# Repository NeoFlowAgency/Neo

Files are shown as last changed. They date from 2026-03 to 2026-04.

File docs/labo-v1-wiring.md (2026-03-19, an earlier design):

# NEO Labo V1 — Guide de câblage rapide

> Projet d'apprentissage : Servo + LEDs + LCD + Clavier 4×4 sur ESP32

---

## Composants nécessaires

- 1× ESP32 DevKit-C
- 1× Servo MG996R (ou SG90 pour commencer)
- 1× LCD 16×2 avec module I2C (adresse 0x27 par défaut)
- 1× Clavier matriciel 4×4
- 3× LEDs (rouge, verte, bleue)
- 3× Résistances 220Ω (une par LED)
- Fils dupont, breadboard

---

## Schéma de branchement

### Servo MG996R (ou SG90)
```
Servo fil BRUN  (GND)    → GND de l'ESP32
Servo fil ROUGE (5V/6V)  → VIN de l'ESP32 (ou alim externe 6V)
Servo fil ORANGE (signal) → GPIO 18
```
> ⚠️ Pour un seul servo en test, le VIN du devkit (5V USB) suffit.
> Pour plusieurs servos lourds, utilise une alim externe.

### LCD 16×2 I2C
```
LCD VCC → 3.3V ou 5V ESP32
LCD GND → GND
LCD SDA → GPIO 21
LCD SCL → GPIO 22
```
> Si l'écran n'affiche rien, tourne le petit potentiomètre bleu
> derrière le module I2C pour ajuster le contraste.

### LEDs
```
LED ROUGE  : anode → GPIO 26 → résistance 220Ω → GND
LED VERTE  : anode → GPIO 27 → résistance 220Ω → GND
LED BLEUE  : anode → GPIO 32 → résistance 220Ω → GND
```
> Sens LED : patte longue = anode (+), patte courte = cathode (−)

### Clavier 4×4
```
 ┌─────────────────────────────────────┐
 │  Clavier  │  Broche  │  GPIO ESP32  │
 ├───────────┼──────────┼──────────────┤
 │  Ligne 1  │   R1     │   GPIO 13    │
 │  Ligne 2  │   R2     │   GPIO 14    │
 │  Ligne 3  │   R3     │   GPIO 16    │
 │  Ligne 4  │   R4     │   GPIO 17    │
 │  Col 1    │   C1     │   GPIO 15    │
 │  Col 2    │   C2     │   GPIO 12    │
 │  Col 3    │   C3     │   GPIO  2    │
 │  Col 4    │   C4     │   GPIO  5    │
 └─────────────────────────────────────┘
```

---

## Librairies Arduino à installer

Dans Arduino IDE → Gestionnaire de bibliothèques :

| Librairie | Auteur |
|---|---|
| `ESP32Servo` | Kevin Harrington |
| `LiquidCrystal I2C` | Frank de Brabander |
| `Keypad` | Mark Stanley / Alexander Brevig |

---

## Contrôles (rappel)

| Touche | Action |
|---|---|
| `1` | Servo → 0° |
| `2` | Servo → 22° |
| `3` | Servo → 45° |
| `4` | Servo → 67° |
| `5` | Servo → 90° (centre) |
| `6` | Servo → 112° |
| `7` | Servo → 135° |
| `8` | Servo → 157° |
| `9` | Servo → 180° |
| `0` | Servo → 90° (centre rapide) |
| `A` | Toggle LED ROUGE |
| `B` | Toggle LED VERTE |
| `C` | Toggle LED BLEUE |
| `D` | Toggle TOUTES les LEDs |
| `*` | Affiche le menu sur LCD |
| `#` | Reset tout (servo 90°, LEDs OFF) |

---

## Problèmes fréquents

**LCD blanc/rien affiché :**
→ Tourne le potentiomètre bleu au dos du module I2C
→ Vérifie l'adresse I2C avec un sketch de scan (chercher "I2C scanner Arduino")

**Servo qui tremble :**
→ Alimente-le en externe (ne pas tirer 5V du port USB de l'ESP32 pour les gros servos)
→ Mets une capa 100µF en parallèle sur l'alim du servo

**Clavier ne répond pas :**
→ Vérifie l'ordre des fils (compte depuis le pin 1 marqué sur le connecteur)
→ Certains claviers ont R1-R4 à gauche, d'autres à droite — inverse les lignes/colonnes si besoin

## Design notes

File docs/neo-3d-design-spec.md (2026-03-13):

# Neo — Spécification 3D (V2)

> Guide de modélisation pour Fusion 360 — imprimante Bambu Lab A1
> Tête Ultron scalée à **250mm de hauteur**

---

## Dimensions de référence : Servo MG996R

```
Longueur : 40.7 mm
Largeur  : 19.7 mm
Hauteur  : 42.9 mm (corps) + ~15 mm axe
Trous de fixation : 49 mm entre-axes (axe long) × 10 mm (axe court)
Diamètre vis fixation : M3
Diamètre axe (horn) : ~6 mm cannelé, 25 dents
Vis de fixation horn : M3 × 8 mm
```

---

## Vue d'ensemble — Hauteurs de la chaîne cinématique

```
┌──────────────────────────────────────────────────────┐
│  TÊTE ULTRON           250 mm  ←── tête scalée       │
│  CAGE INTERNE TÊTE      ~50 mm (structure interne)   │
│  SUPPORT TÊTE           50 mm  (S3 + bras S4/palier) │
│  COU                    80 mm  (creux, passage câble) │
│  BUSTE                 130 mm  (torse Ultron stylisé) │
│  BASE                  100 mm  (électronique)         │
├──────────────────────────────────────────────────────┤
│  HAUTEUR TOTALE        ~610 mm                        │
│  (sans compter les pieds de l'antenne/décoration)     │
└──────────────────────────────────────────────────────┘
```

---

## Contraintes Bambu Lab A1 (volume 256×256×256 mm)

| Pièce | Dims max estimées | Imprimable d'un coup ? |
|---|---|---|
| Tête Ultron | ~180×200×250 mm | ✅ Oui |
| Base | 200×160×100 mm | ✅ Oui |
| Buste | 120×90×130 mm | ✅ Oui |
| Cou | Ø65×80 mm | ✅ Oui |
| Support tête | 160×90×50 mm | ✅ Oui |
| Cage interne | ~170×190×50 mm | ✅ Oui |

> ⚠️ Si la tête Ultron dépasse 256mm en largeur ou profondeur après scaling,
> elle devra être coupée en 2 moitiés (gauche/droite) et collée à la résine.

---

## Passage de câbles — Principe général

```
Base → Buste : gouttière centrale Ø12 mm (4× câbles servo + alim)
Buste → Cou  : gouttière centrale Ø12 mm
Cou → Support: gouttière centrale Ø10 mm
Support → Cage: 2× trous Ø6 mm sur les bras latéraux
```

Câbles concernés par pièce :
- **Base** : ESP32 USB (charge/prog), câble alim 5V/6V servos, câble écran LCD, câble clavier
- **Buste** : câble S1 (sort par bas) + câbles S2/S3/S4 (transit vers haut)
- **Cou** : câbles S3 + S4 en transit
- **Support** : câble S4 local

---

## PIÈCE 1 — BASE

**Fonction :** Boîtier principal — contient toute l'électronique — porte le Servo S1 (rotation torse)

**Dimensions extérieures :**
```
Longueur : 200 mm
Largeur  : 160 mm
Hauteur  : 100 mm
Épaisseur parois : 3 mm (PETG) ou 2.5 mm (PLA+)
```

**Façade AVANT (interface utilisateur) :**
```
Écran LCD 16×2 I2C :
  Fenêtre découpe : 74 mm × 25 mm
  Position : centré horizontalement, à 12 mm du bord supérieur

Clavier matriciel 4×4 :
  Fenêtre découpe : 72 mm × 72 mm
  Position : centré horizontalement, à 10 mm du bord inférieur
  (espace entre LCD et clavier : ~25 mm pour câblage)
```

**Façade LATÉRALE gauche :**
```
Interrupteur marche/arrêt (bouton poussoir ou toggle) : trou Ø7 mm
Potentiomètre volume/réglage : trou Ø7 mm
Passage USB-C ESP32 (charge/programmation) : découpe 10×5 mm
```

**Façade LATÉRALE droite :**
```
Passage câbles servos (gaine spirale) : passage Ø12 mm avec guide
```

**Dessus de la BASE :**
```
Logement servo S1 (MG996R À PLAT, axe vers le haut) :
  Cavité : 44 mm × 22 mm × 25 mm
  4 × trous M3, entraxe 49 mm × 10 mm
  Axe centré en largeur, décalé de 25 mm vers l'arrière
  Ouverture Ø8 mm pour l'axe S1 (vers le haut)

Passage câbles (côté arrière du servo) : gouttière 12×8 mm
```

**Intérieur BASE :**
```
ESP32 DevKit-C (55×28 mm) :
  4 × plots M2.5 hauteur 5 mm, en bas à gauche de la base
  Accès USB-C vers le trou latéral

Porte-batterie / régulateur 6V :
  Zone réservée 80×40 mm côté arrière droit

Gouttières câbles : 2 × gouttières latérales 10 mm de large
```

**Matériau :** PETG
**Infill :** 25%, gyroïde
**Couleur suggérée :** Gris foncé ou noir

---

## PIÈCE 2 — BUSTE

**Fonction :** Torse de Neo — tourne avec S1 — porte S2 (rotation cou)

**Dimensions :**
```
Largeur bas  : 120 mm (s'emboîte sur la base)
Largeur haut : 80 mm
Profondeur   : 75 mm
Hauteur      : 130 mm
Épaisseur paroi : 3 mm
```

**Bas du buste — adaptateur horn S1 :**
```
Plateau circulaire Ø58 mm, épaisseur 5 mm
  4 × trous M3 sur cercle Ø42 mm (vis horn standard)
  Trou central Ø6.5 mm (passage axe)
  Ce plateau descend DANS la base (jeu vertical +0.3 mm → rotation libre)
```

**Haut du buste — logement S2 :**
```
S2 monté À PLAT (axe vers le haut)
Cavité : 44 mm × 22 mm × 25 mm
4 × trous M3, entraxe 49 mm × 10 mm
Axe centré en largeur et profondeur
Ouverture Ø8 mm vers le haut
```

**Passage câbles :**
```
Gouttière centrale verticale Ø12 mm (câbles S2/S3/S4 en transit)
```

**Forme esthétique :**
```
Section trapézoïdale (plus large en bas)
Chanfreins 5 mm sur les arêtes verticales
Style "torse Ultron" (légers creux sur les flancs, optionnel)
```

**Matériau :** PETG
**Infill :** 30%, gyroïde

---

## PIÈCE 3 — COU

**Fonction :** Relie buste et support tête — tourne avec S2 — porte S3 (inclinaison)

**Dimensions :**
```
Diamètre extérieur : 65 mm
Diamètre intérieur : 59 mm (paroi 3 mm)
Hauteur : 80 mm
```

**Bas du cou — adaptateur horn S2 :**
```
Identique aux autres : plateau Ø58 mm, vis horn sur Ø42 mm
Jeu +0.3 mm par rapport au logement dans le buste
```

**Haut du cou — logement S3 :**
```
S3 monté HORIZONTALEMENT (axe perpendiculaire à l'axe de rotation du cou)
Cavité ouverte latéralement : 44 mm × 22 mm × 45 mm
4 × trous M3, entraxe 49 mm × 10 mm
L'axe de S3 pointe vers la gauche ou la droite (inclinaison tête)
```

**Passage câbles :**
```
Canal central Ø12 mm sur toute la hauteur (câbles S3 + S4)
```

**Matériau :** PETG
**Infill :** 35%, gyroïde (pièce sous contrainte mécanique)

---

## PIÈCE 4 — SUPPORT TÊTE

**Fonction :** Plateau en croix — reçoit horn S3 — porte S4 (inclinaison haut/bas) + palier opposé

```
⚠️ Architecture servos :
  S3 (dans le cou) : rotation GAUCHE/DROITE de la tête
  S4 (dans ce support) : inclinaison HAUT/BAS de la tête
  Côté opposé à S4 : palier libre (axe M4 + rondelles téflon)
```

**Dimensions :**
```
Corps central     : 90 mm × 90 mm × 50 mm
Bras droit (S4)   : 35 mm long × 30 mm large × 45 mm haut
Bras gauche (palier) : 35 mm long × 30 mm large × 45 mm haut
Largeur totale avec bras : 160 mm
```

> 160 mm < largeur tête (~180 mm) → ✅ La tête peut s'emboîter sans interférence

**Bas du support — horn S3 :**
```
Plateau Ø58 mm, 4 × vis M3 sur Ø42 mm
```

**Bras droit — logement S4 :**
```
S4 monté VERTICALEMENT dans le bras droit
Cavité : 44 mm × 22 mm × 45 mm
Axe de S4 pointe vers l'INTÉRIEUR (vers l'axe de la tête)
4 × trous M3, entraxe 49 mm × 10 mm
```

**Bras gauche — palier libre :**
```
Trou traversant Ø4.3 mm (vis M4 × 40 mm comme axe)
2 × rondelles téflon comme palier (épaisseur 1 mm chacune)
Écrou borgne M4 côté extérieur
```

**Passage câbles :**
```
Rainure 8×6 mm de S4 vers le centre (câble servo S4)
```

**Matériau :** PETG haute densité
**Infill :** 40%, gyroïde (pièce critique — supporte le poids de la tête)

---

## PIÈCE 5 — CAGE INTERNE TÊTE

**Fonction :** Armature rigide à l'intérieur de la tête Ultron — connecte S4 et le palier à la coque

**⚠️ Cette pièce se modélise APRÈS avoir importé la tête scalée dans Fusion 360.**
Les dimensions ci-dessous sont estimatives — à confirmer après mesure dans Fusion.

**Estimation basée sur tête Ultron 250mm de haut :**
```
Anneau supérieur (s'insère dans le crâne) :
  Diamètre extérieur : ~170 mm (à mesurer dans Fusion)
  Épaisseur anneau   : 4 mm
  Hauteur anneau     : 15 mm
  → Se fixe par collage epoxy ou 3 clips imprimés

2 bras latéraux (descendent de l'anneau vers S4 et le palier) :
  Longueur bras       : ~80 mm
  Section bras        : 20 mm × 10 mm (rectangle plein)
  Espacement bras     : 160 mm (doit correspondre à l'entraxe du SUPPORT TÊTE)

Extrémité bras droit — adaptateur horn S4 :
  Plateau Ø58 mm, 4 × M3 sur Ø42 mm, trou central Ø6.5 mm

Extrémité bras gauche — palier :
  Trou Ø4.3 mm (axe M4 libre)
```

**Passage câbles internes :**
```
2 × passages Ø6 mm sur les bras (câbles éventuels dans la tête)
```

**Étapes dans Fusion 360 :**
```
1. Importer la tête Ultron scalée (STL → Corps maillage)
2. Outils → Inspecter → Mesurer → diamètre intérieur crâne
3. Mesurer hauteur intérieure disponible
4. Modéliser la cage en SOLIDE (pas maillage) sur ces mesures
5. Vérifier le jeu de rotation (la cage tourne avec la tête)
```

**Matériau :** PETG
**Infill :** 40%

---

## Tolérances d'impression (Bambu Lab A1)

| Type d'ajustement | Jeu recommandé |
|---|---|
| Pièces emboîtées glissantes | +0.3 mm sur le diamètre |
| Trous de vis M3 | Ø3.2 mm |
| Trous de vis M4 | Ø4.2 mm |
| Horn servo (plateau Ø58) | Ø58.3 mm en creux |
| Axe palier libre M4 | Ø4.3 mm |
| Passage câbles (gaine Ø10) | Ø10.5 mm |

---

## Ordre d'assemblage mécanique

```
1.  Visser S1 dans la BASE (cavité dessus)
2.  Faire passer tous les câbles S2/S3/S4 dans la gouttière BASE
3.  Monter le BUSTE sur le horn de S1
4.  Visser S2 dans le BUSTE (haut)
5.  Faire passer les câbles S3/S4 dans le COU
6.  Monter le COU sur le horn de S2
7.  Visser S3 dans le COU (horizontal)
8.  Faire passer le câble S4 dans le SUPPORT
9.  Monter le SUPPORT TÊTE sur le horn de S3
10. Visser S4 dans le bras droit du SUPPORT
11. Insérer l'axe palier M4 + rondelles dans le bras gauche
12. Coller/clipser la CAGE INTERNE dans la tête Ultron
13. Connecter cage → horn S4 (droite) + axe palier (gauche)
14. ✅ Tester les rotations à la main avant de brancher les servos
```

---

## Checklist avant modélisation Fusion 360

- [ ] Lancer `scale_ultron_head.py` sur ton PC Windows
- [ ] Noter la largeur (X) et profondeur (Y) de la tête après scaling
- [ ] Importer le STL tête scalée dans Fusion 360
- [ ] Mesurer le diamètre intérieur du crâne (outil Inspecter → Mesurer)
- [ ] Mesurer la hauteur intérieure disponible
- [ ] Reporter ces 2 mesures dans la section PIÈCE 5 ci-dessus
- [ ] Hauteur totale robot souhaitée : __ mm (optionnel, pour ajuster le COU)
- [ ] Longueur câbles servos disponibles : __ mm (impacte gouttières)

---

## Résumé des matériaux et quantités

| Pièce | Matériau | Infill | Couleur |
|---|---|---|---|
| BASE | PETG | 25% gyroïde | Noir/gris |
| BUSTE | PETG | 30% gyroïde | Argent (Ultron) |
| COU | PETG | 35% gyroïde | Argent |
| SUPPORT TÊTE | PETG | 40% gyroïde | Noir (caché) |
| CAGE INTERNE | PETG | 40% gyroïde | Noir (caché) |
| TÊTE ULTRON | PLA+ | 20% gyroïde | Argent / Or |

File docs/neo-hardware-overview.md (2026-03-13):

# Neo — Vue d'ensemble Hardware

## 1. Architecture générale

```
┌─────────────────────────────────────────────────────┐
│                    VPS (Cloud)                       │
│   Flask + SocketIO ←→ OpenClaw AI                   │
└────────────────────┬────────────────────────────────┘
                     │ WiFi / MQTT
┌────────────────────▼────────────────────────────────┐
│                  ESP32 (cerveau)                     │
│  I2S Mic  │  I2S Amp  │  Servos  │  LCD  │  Keypad  │
└─────┬─────┴─────┬─────┴────┬─────┴───┬───┴────┬─────┘
      │           │          │         │        │
  INMP441    MAX98357    4×MG996R   LCD 16x2  Keypad
  (micro)    (ampli)    + 1×SG90   + RTC DS  4×4
                           │
                        Alimentation
                      5V / 5A externe
```

## 2. Mécanique & Mouvements (V1)

```
         ┌──────────────────────┐
         │   TÊTE (creux)       │  ← tous les composants légers ici
         │   LCD, ESP32, mic... │
         └──────────┬───────────┘
                    │ câbles internes
         ┌──────────▼───────────┐
         │   COU                │  ← Servo 3 : inclinaison gauche/droite
         │   Servo 4 : haut/bas │     (pan)
         └──────────┬───────────┘
                    │
         ┌──────────▼───────────┐
         │   TORSE              │  ← Servo 2 : rotation cou (yaw)
         └──────────┬───────────┘
                    │
         ┌──────────▼───────────┐
         │   BASE               │  ← Servo 1 : rotation torse (base)
         │   Alimentation       │
         │   Switch, Potentio   │
         └──────────────────────┘
```

| Servo | Emplacement | Mouvement | Modèle | Plage |
|---|---|---|---|---|
| S1 | Base | Rotation torse (yaw) | MG996R | 30°–150° |
| S2 | Torse | Rotation cou (yaw) | MG996R | 40°–140° |
| S3 | Cou | Inclinaison tête gauche/droite (roll) | MG996R | 50°–130° |
| S4 | Cou | Inclinaison tête haut/bas (pitch) | MG996R | 50°–130° |
| S5 | Tête | Bouche (open/close) | SG90 | 0°–45° |

## 3. Plan GPIO ESP32

> L'ESP32 dispose de ~30 GPIO utilisables. Voici l'attribution complète.

| GPIO | Label DevKit | Fonction | Composant | Notes |
|---|---|---|---|---|
| 0  | D0  | Keypad Col 4 | Keypad 4×4 | Strapping pin — OK après boot |
| 2  | D2  | Keypad Col 3 | Keypad 4×4 | Strapping pin — OK après boot |
| 4  | D4  | I2C SDA | LCD 16x2 + RTC | Bus I2C partagé |
| 5  | D5  | I2C SCL | LCD 16x2 + RTC | Bus I2C partagé |
| 12 | D12 | Keypad Col 2 | Keypad 4×4 | Strapping pin — OK après boot |
| 13 | D13 | Buzzer | KSG3603 | Via résistance 100Ω |
| 14 | D14 | I2S SCK (mic) | INMP441 | Horloge micro |
| 15 | D15 | I2S WS (mic) | INMP441 | Word Select micro |
| 16 | RX2 | Keypad Row 1 | Keypad 4×4 | INPUT_PULLUP interne |
| 17 | TX2 | Keypad Row 2 | Keypad 4×4 | INPUT_PULLUP interne |
| 18 | D18 | Servo S1 — Torse | MG996R | PWM |
| 19 | D19 | Servo S2 — Cou | MG996R | PWM |
| 21 | D21 | Servo S3 — Roll | MG996R | PWM |
| 22 | D22 | I2S DIN (ampli) | MAX98357 | Data audio |
| 23 | D23 | Servo S4 — Pitch | MG996R | PWM |
| 25 | D25 | I2S LRC (ampli) | MAX98357 | Word Select ampli |
| 26 | D26 | I2S BCLK (ampli) | MAX98357 | Bit Clock ampli |
| 27 | D27 | Servo S5 — Bouche | SG90 | PWM |
| 32 | D32 | I2S SD (mic) | INMP441 | Données micro (INPUT) |
| 33 | D33 | Keypad Col 1 | Keypad 4×4 | OUTPUT |
| 34 | D34 | Keypad Row 3 | Keypad 4×4 | INPUT seul — 10kΩ pullup externe |
| 35 | D35 | Keypad Row 4 | Keypad 4×4 | INPUT seul — 10kΩ pullup externe |
| 36 | VP  | Switch | Interrupteur | INPUT seul — 10kΩ pullup externe |
| 39 | VN  | Potentiomètre | Volume/réglage | ADC INPUT |

> **Note LCD :** Le LCD 16x2 doit avoir un module I2C (PCF8574) soudé derrière. À commander si absent (~1€). Adresse par défaut : `0x27`.

> **Note RTC :** Partage le même bus I2C que le LCD (même SDA/SCL, GPIO 4/5). Adresse `0x68`, aucun conflit.

> **Note GPIO input-only :** GPIO 34, 35, 36 sont entrées uniquement et n'ont PAS de pull-up interne. Ajouter des résistances 10kΩ externes entre ces pins et 3.3V (voir guide de câblage).

## 4. Alimentation — POINT CRITIQUE ⚠️

### Problème : le LiPo 1S 300mAh est insuffisant

| Composant | Tension | Courant typique | Courant max (stall) |
|---|---|---|---|
| MG996R ×4 | 5V–6V | 4 × 500mA = 2A | 4 × 2.5A = **10A** |
| SG90 ×1 | 5V | 100mA | 600mA |
| ESP32 | 3.3V (via régulateur 5V) | 240mA | 500mA |
| LCD + RTC | 5V | 50mA | — |
| Micro + Ampli | 3.3V | 50mA | — |
| **TOTAL estimé** | | **~2.5A** repos | **>10A** bloqué |

La LiPo 1S 3.7V 300mAh = **300mAh à 3.7V** → inutilisable pour les servos.

### Solution recommandée pour V1 (filaire — sur secteur)

```
Prise secteur
     │
[Alimentation 5V / 5A]  ← Commander : ~10€ (type "5V 5A DC adapter")
     │
     ├── [Rail 5V servo]  → S1, S2, S3, S4 (MG996R) + S5 (SG90)
     │        │
     │    [Condensateur 1000µF 10V]  ← absorbe les pics de courant
     │
     └── [Régulateur 3.3V ou pin VIN ESP32]  → ESP32, LCD, RTC, Mic, Ampli
```

> L'ESP32 accepte 5V sur sa pin VIN (il a un régulateur 3.3V interne).
> **Ne jamais alimenter les servos depuis les pins 3.3V ou 5V de l'ESP32** — il ne peut fournir que ~40mA par pin.

### Usage du LiPo 1S 300mAh

Garde-le pour un usage futur (alimentation de secours d'un Arduino Nano, ou capteur BLE autonome).

### Usage des MB102 Power Modules

Les modules MB102 (3.3V/5V depuis jack barrel ou USB) sont utiles pour :
- Alimenter les breadboards de prototypage
- Alimenter séparément les modules capteurs lors des tests

## 5. Composants V1 — tableau de décision

| Composant | V1 | Raison |
|---|-----|---|
| ESP32 Type-C | ✅ | Cerveau principal |
| 4× MG996R | ✅ | Mouvements torse/cou/tête |
| 1× SG90 | ✅ | Bouche (optionnel) |
| INMP441 | ✅ | Micro I2S — entrée voix |
| MAX98357 | ✅ | Ampli I2S — sortie voix |
| LCD 16x2 | ✅ | Affichage état/texte |
| MH RTC | ✅ | Heure locale même sans WiFi |
| Buzzer KSG3603 | ✅ | Feedback sonore simple |
| Keypad 4×4 | ✅ | Contrôle manuel |
| Switch | ✅ | Marche/Arrêt ou mode |
| Potentiomètre | ✅ | Volume ou réglage vitesse |
| KY-037 sound sensor | 🔶 V2 | Détection son/voix (INMP441 suffit en V1) |
| SN74HC595 | 🔶 V2 | Utile si besoin >30 LEDs |
| Arduino Nano ×3 | 🔶 V2/V3 | Co-processeurs si ESP32 saturé |
| LiPo 1S 300mAh | ❌ V1 | Trop petite, garde pour autre projet |
| TT motors + roues | 🔶 V2 | Déplacement — pas prévu en V1 |
| Capteur eau | ❌ | Pas pertinent pour Neo |
| Capteur humidité | 🔶 | Capteur ambiance (optionnel) |

## 6. À commander pour compléter V1

| Composant | Pourquoi | Coût estimé |
|---|---|---|
| **Alimentation 5V / 5A** (jack DC ou USB-C PD) | Indispensable pour les servos | ~8–12€ |
| **Haut-parleur 3W 4Ω ou 8Ω** (petit, ~40mm) | Nécessaire pour le MAX98357 | ~3–5€ |
| **Module I2C pour LCD 16x2** (PCF8574) | Libère 4 GPIO, câblage simple | ~2€ |
| **Condensateur 1000µF 10V** | Stabilise le rail servo | ~1€ |

## 7. Roadmap versions

### V1 — Buste expressif (objectif actuel)
- [x] Backend VPS (Flask + MQTT + OpenClaw)
- [x] Interface web de contrôle
- [ ] Firmware ESP32 (MQTT, servos, LCD, micro, ampli)
- [ ] Schéma électronique complet
- [ ] Structure 3D de base (torse + cou + tête) → voir **[neo-3d-design-spec.md](neo-3d-design-spec.md)**
  - [ ] PIÈCE 1 : BASE (boîtier électronique + S1)
  - [ ] PIÈCE 2 : BUSTE (torse, tourne sur S1, porte S2)
  - [ ] PIÈCE 3 : COU (tourne sur S2, porte S3)
  - [ ] PIÈCE 4 : SUPPORT TÊTE (reçoit S3, porte S4 + palier)
  - [ ] PIÈCE 5 : CAGE INTERNE TÊTE (adaptateur cage → tête Ultron)
- [ ] Câblage final

### V2 — Mobilité
- [ ] Base roulante (TT motors + roues)
- [ ] Détection obstacle
- [ ] Navigation simple

### V3 — Expressions faciales
- [ ] Micro servos pour yeux/sourcils
- [ ] Impression 3D tête expressive (Bambu Lab A1)
- [ ] Lèvres animées (SG90 amélioré)

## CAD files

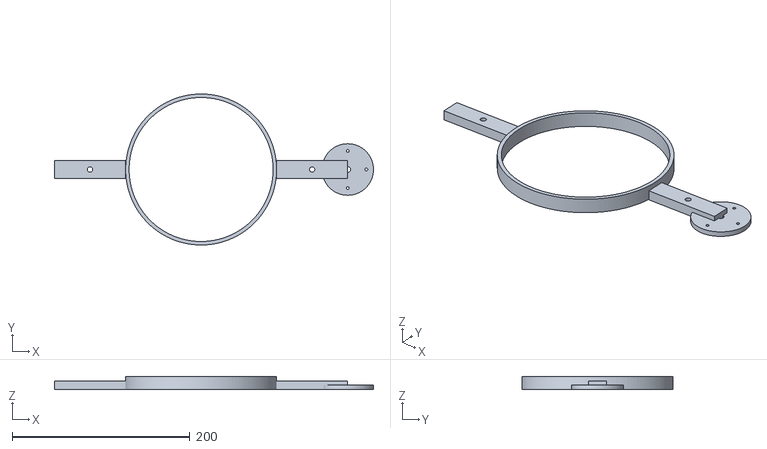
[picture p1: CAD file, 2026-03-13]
stl_output/neo_cage_interne.stl
359.0 x 169.9 x 15.0

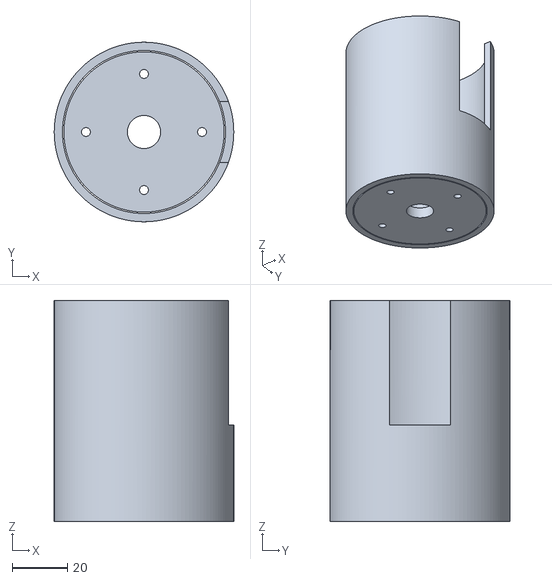
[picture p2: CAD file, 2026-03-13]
stl_output/neo_cou.stl
65.0 x 65.0 x 80.0

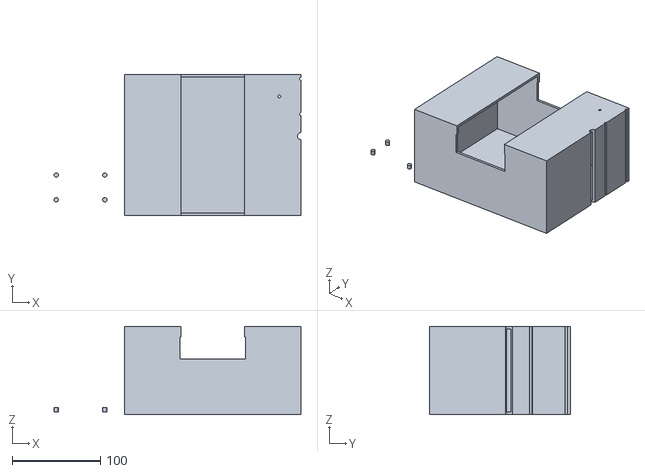
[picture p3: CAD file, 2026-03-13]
stl_output/neo_base.stl
279.5 x 160.0 x 100.0

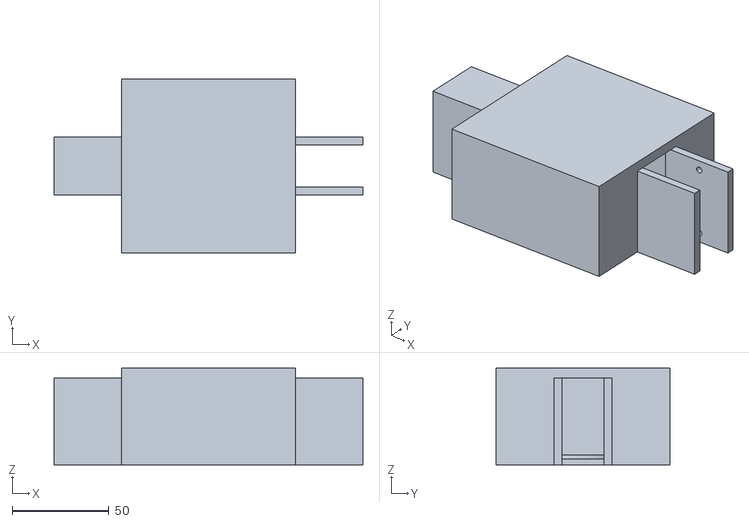
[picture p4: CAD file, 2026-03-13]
stl_output/neo_support_tete.stl
160.0 x 90.0 x 50.0

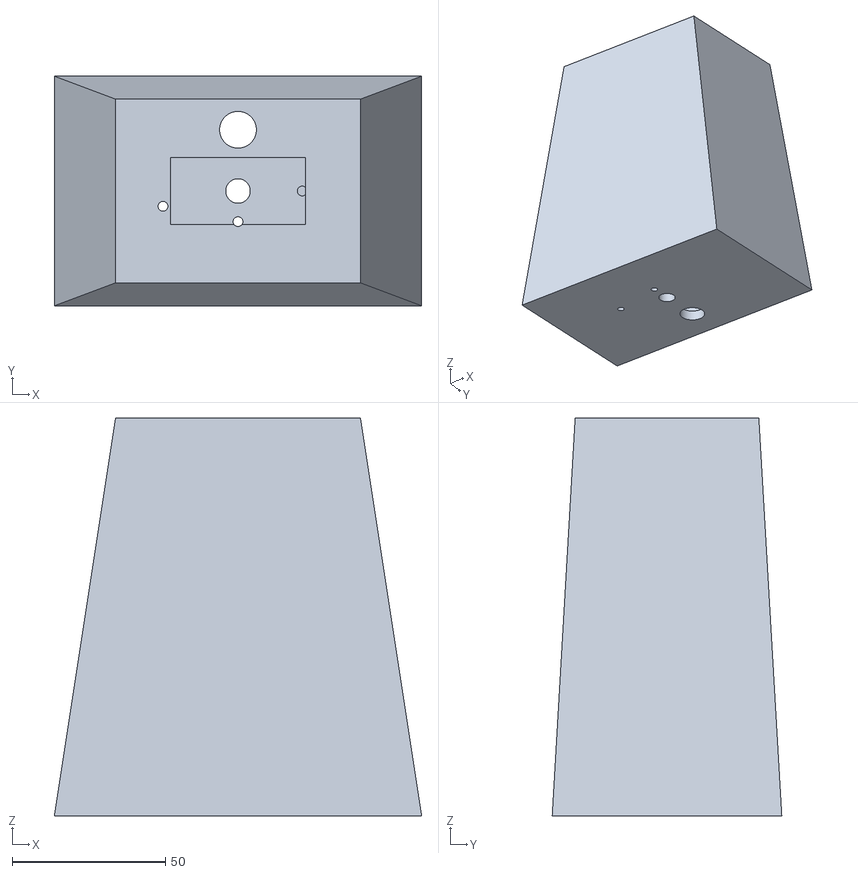
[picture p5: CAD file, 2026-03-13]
stl_output/neo_buste.stl
120.0 x 75.0 x 130.0

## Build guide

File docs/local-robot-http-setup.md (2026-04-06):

# NEO Local Robot Setup (PC + ESP32 en HTTP)

> Ce guide est pensé pour **tout faire en local sur ton PC** (Ollama, Flask, TTS),
> avec l'ESP32 connecté en Wi-Fi au même réseau et piloté en HTTP.

## 1) Architecture finale

- **Téléphone (web app)**: reconnaissance vocale (`Web Speech API`) puis `POST /ask` vers le PC.
- **PC local (Flask)**:
  1. reçoit le prompt,
  2. appelle **Ollama/Gemma**,
  3. force une réponse JSON structurée,
  4. génère `response.wav` (TTS pyttsx3),
  5. envoie `POST /action` vers l'ESP32.
- **ESP32**: exécute l'action physique servo (`turn_left`, `turn_right`, `nod`, `none`).

## 2) Pré-requis PC (local)

- Python 3.10+
- Ollama installé et démarré
- Modèle Gemma installé:

```bash
ollama pull gemma:4b
```

Installer les dépendances Python:

```bash
pip install -r requirements.txt
```

> Si `pyttsx3` pose problème audio selon ton OS, installe aussi les drivers système :
> - Linux Debian/Ubuntu : `sudo apt-get install espeak ffmpeg libespeak1`
> - macOS : voix natives déjà disponibles (NSSpeechSynthesizer)
> - Windows : SAPI5 est utilisé automatiquement

## 3) Préparer ton environnement local (important)

Depuis la racine du repo, crée un environnement virtuel :

```bash
python -m venv .venv
source .venv/bin/activate      # macOS/Linux
# .venv\\Scripts\\activate     # Windows PowerShell
pip install --upgrade pip
pip install -r requirements.txt
```

Vérifie qu'Ollama tourne sur ton PC :

```bash
ollama serve
```

Dans un 2e terminal :

```bash
ollama list
ollama run gemma:4b "Réponds en JSON: {\"text\":\"ok\",\"action\":\"none\"}"
```

## 4) Lancer le serveur Flask local

Depuis la racine du repo:

```bash
export ESP32_URL="http://192.168.1.50"   # IP locale de ton ESP32
export OLLAMA_MODEL="gemma:4b"
export OLLAMA_URL="http://127.0.0.1:11434/api/generate"
python robot_server.py
```

Le serveur écoute par défaut sur `http://0.0.0.0:5000`.

## 5) Récupérer l'IP locale du PC

### Linux
```bash
hostname -I
```

### macOS
```bash
ipconfig getifaddr en0
```

### Windows (PowerShell)
```powershell
ipconfig
```

Prends l'IP du réseau Wi-Fi local (ex: `192.168.1.10`).

## 6) Tester API du serveur local (sans téléphone)

```bash
curl -X POST http://127.0.0.1:5000/ask \
  -H "Content-Type: application/json" \
  -d '{"prompt":"Tourne la tête à droite"}'
```

Réponse attendue:

```json
{
  "text": "...",
  "action": "turn_right",
  "audio_url": "http://PC_IP:5000/audio/response.wav"
}
```

Tu peux aussi tester l'audio généré directement dans ton navigateur :

```
http://127.0.0.1:5000/audio/response.wav
```

## 7) Mettre la web app sur ton téléphone

- Méthode simple en local : depuis `mobile_webapp/` lance un petit serveur web :

```bash
cd mobile_webapp
python -m http.server 8080
```

- Sur ton téléphone (même Wi-Fi), ouvre :
  - `http://PC_IP:8080`
- Dans le champ URL serveur, mets :
  - `http://PC_IP:5000`

- Alternative : publier `mobile_webapp/` sur GitHub Pages, puis garder l'URL Flask locale.
- Renseigne l'URL du serveur Flask avec IP LAN du PC: `http://PC_IP:5000`.
- Clique **Parler**, puis **Envoyer le texte**.
- Vérifie:
  - texte affiché,
  - action affichée,
  - audio qui se joue,
  - mouvement du servo sur ESP32.

## 8) Flasher et tester ESP32 (Arduino IDE)

Fichier firmware: `wokwi/neo_http_robot.ino`

1. Ouvre Arduino IDE.
2. Installe les cartes **ESP32 by Espressif Systems**.
3. Installe les librairies :
   - `ESP32Servo`
   - `ArduinoJson`
4. Ouvre `wokwi/neo_http_robot.ino`.
5. Mets ton SSID/mot de passe Wi-Fi dans le `.ino`.
6. Sélectionne la bonne carte (ex: ESP32 Dev Module) + port série.
7. Compile puis flash.
8. Ouvre le moniteur série (115200) et note l'IP affichée.
9. Test direct:

```bash
curl -X POST http://ESP32_IP/action \
  -H "Content-Type: application/json" \
  -d '{"action":"nod"}'
```

Tu peux aussi vérifier la santé:

```bash
curl http://ESP32_IP/health
```

## 9) Check-list de debug (si ça ne marche pas)

1. **Téléphone et PC sur le même Wi-Fi** (important).
2. Firewall du PC autorise le port `5000`.
3. Test depuis PC :
   - `curl http://127.0.0.1:5000/health`
4. Test depuis téléphone :
   - `http://PC_IP:5000/health`
5. Test ESP32 :
   - `curl http://ESP32_IP/health`
6. Test chaîne complète :
   - `POST /ask` puis vérifier mouvement servo.

## 10) Extension prévue (bonus)

Le firmware est prêt pour extension:

- placeholder configuration audio I2S (`AudioConfig`),
- ajout facile de nouvelles actions via `runAction`,
- synchronisation voix+mouvement côté Python (ajouter timeline d'actions avant/pendant TTS).

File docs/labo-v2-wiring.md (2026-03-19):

# NEO Labo V2 — Câblage

> Servo + Potentiomètre + MAX98357 + Détecteur son + Clavier 4×4

---

## Schéma de branchement

### Potentiomètre (3 broches)
```
Broche GAUCHE  → GND
Broche CENTRE  → GPIO 34  (signal analogique)
Broche DROITE  → 3.3V
```
> ⚠️ Utilise 3.3V, PAS 5V — l'ADC de l'ESP32 supporte max 3.3V

---

### Servo MG996R
```
Fil BRUN   (GND)    → GND
Fil ROUGE  (alim)   → alim externe 5V-6V  (ou VIN si juste 1 servo léger)
Fil ORANGE (signal) → GPIO 18
```

---

### MAX98357 (ampli I2S)
```
MAX98357  →  ESP32
VIN       →  5V (VIN du devkit)
GND       →  GND
BCLK      →  GPIO 26
LRC       →  GPIO 25
DIN       →  GPIO 22
SD        →  laisser non connecté (ou 3.3V pour activer en permanence)
```
> Le haut-parleur se branche sur les bornes "+" et "−" du MAX98357

---

### Détecteur de son (module 3 broches MH-M38)
```
VCC → 3.3V
GND → GND
OUT → GPIO 35   ← détection clap/son
```
> **OUT = LOW quand un son est détecté**, HIGH au repos.
>
> La sensibilité se règle avec le petit potentiomètre bleu sur le module.
> La LED "开关指示" (switch) s'allume quand un son est détecté.
> Tourne le potentiomètre jusqu'à ce qu'elle réagisse à tes claps.

**Si ça déclenche en permanence sans son :**
→ Tourne le potentiomètre dans le sens inverse (réduire la sensibilité)

**Si ça ne déclenche jamais :**
→ Tourne le potentiomètre pour augmenter la sensibilité, ou change dans le code :
```cpp
bool soundDetected = (digitalRead(PIN_DET_OUT) == LOW);
// → remplace LOW par HIGH
```

---

### Clavier 4×4
```
Clavier  →  GPIO ESP32
R1 (haut) →  13
R2        →  14
R3        →  16
R4 (bas)  →  17
C1 (gche) →  15
C2        →  12
C3        →   2
C4 (dte)  →   5
```

---

## Librairies Arduino nécessaires

| Librairie | Auteur |
|---|---|
| `ESP32Servo` | Kevin Harrington |
| `Keypad` | Mark Stanley / Alexander Brevig |

L'I2S est intégré dans le core ESP32 — pas d'installation supplémentaire.

---

## Contrôles

| Touche | Action |
|---|---|
| `1`–`7` | Joue Do Ré Mi Fa Sol La Si |
| `8` | Mélodie : Frère Jacques |
| `9` | Alarme 3 bips montants |
| `0` | Silence (coupe le son) |
| `A` | Toggle balayage auto du servo |
| `B` | Servo → 0° |
| `C` | Servo → 90° |
| `D` | Servo → 180° |
| `*` | Toggle détection clap ON/OFF |
| `#` | Reset tout |

**Potentiomètre** = contrôle le servo en continu (désactivé si sweep ON)

**Clap** = le servo fait un sursaut + bip

---

## Dépannage

**Pas de son du speaker :**
→ Vérifie BCLK/LRC/DIN bien branchés
→ Vérifie que SD du MAX98357 n'est pas tiré vers GND
→ Dans Arduino IDE, sélectionne bien "ESP32 Dev Module" comme carte

**Potentiomètre fait trembler le servo :**
→ Normal, le code filtre les variations < 2° — si encore trop instable,
   augmente le seuil dans le code : `if (abs(angle - servoAngle) >= 5)`

**Détecteur son déclenche en permanence :**
→ Tourne le potentiomètre du module pour réduire la sensibilité
→ Ou change `LOW` en `HIGH` dans le code (ligne soundDetected)

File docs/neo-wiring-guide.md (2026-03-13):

# Neo — Guide de câblage complet

> **Référence principale.** Ce document décrit la connexion exacte de chaque
> composant à l'ESP32. Le fichier Wokwi (`docs/wokwi/diagram.json`) est
> basé sur ce tableau.

---

## Plan GPIO ESP32 (FINAL)

> L'ESP32 DevKit V1 a 20 GPIO réguliers + 4 entrées uniquement (34/35/36/39).
> Le plan ci-dessous utilise les 24 GPIO disponibles sans conflit.

| GPIO | Label DevKit | Fonction | Composant | Direction | Notes |
|---|---|---|---|---|---|
| 0 | D0  | Keypad Col 4 | Keypad 4×4 | OUTPUT | Strapping pin — OK après boot |
| 2 | D2  | Keypad Col 3 | Keypad 4×4 | OUTPUT | Strapping pin — OK après boot |
| 4 | D4  | I2C SDA | LCD 16×2 + RTC | I/O | Bus I2C partagé |
| 5 | D5  | I2C SCL | LCD 16×2 + RTC | OUTPUT | Bus I2C partagé |
| 12 | D12 | Keypad Col 2 | Keypad 4×4 | OUTPUT | Strapping pin — OK après boot |
| 13 | D13 | Buzzer | KSG3603 | OUTPUT | Via résistance 100Ω |
| 14 | D14 | I2S SCK (mic) | INMP441 | OUTPUT | Horloge I2S micro |
| 15 | D15 | I2S WS (mic) | INMP441 | OUTPUT | Word Select I2S micro |
| 16 | RX2 | Keypad Row 1 | Keypad 4×4 | INPUT_PULLUP | |
| 17 | TX2 | Keypad Row 2 | Keypad 4×4 | INPUT_PULLUP | |
| 18 | D18 | Servo S1 — Torse | MG996R n°1 | PWM | Rotation base |
| 19 | D19 | Servo S2 — Cou | MG996R n°2 | PWM | Rotation gauche/droite |
| 21 | D21 | Servo S3 — Roll | MG996R n°3 | PWM | Inclinaison latérale |
| 22 | D22 | I2S DIN (ampli) | MAX98357 | OUTPUT | Data audio |
| 23 | D23 | Servo S4 — Pitch | MG996R n°4 | PWM | Inclinaison haut/bas |
| 25 | D25 | I2S LRC (ampli) | MAX98357 | OUTPUT | Word Select ampli |
| 26 | D26 | I2S BCLK (ampli) | MAX98357 | OUTPUT | Bit clock ampli |
| 27 | D27 | Servo S5 — Bouche | SG90 | PWM | Expression bouche |
| 32 | D32 | I2S SD (mic) | INMP441 | INPUT | Données micro entrant |
| 33 | D33 | Keypad Col 1 | Keypad 4×4 | OUTPUT | |
| 34 | D34 | Keypad Row 3 | Keypad 4×4 | INPUT seul | ⚠ Ajouter 10kΩ pullup → 3.3V |
| 35 | D35 | Keypad Row 4 | Keypad 4×4 | INPUT seul | ⚠ Ajouter 10kΩ pullup → 3.3V |
| 36 | VP  | Switch (interrupteur) | Switch | INPUT seul | ⚠ Ajouter 10kΩ pullup → 3.3V |
| 39 | VN  | Potentiomètre | Potentiomètre | ADC INPUT | Entrée analogique |

---

## Câblage par composant

### 1. Servos MG996R (×4) + SG90 (×1)

> ⚠️ **IMPORTANT** : Ne jamais alimenter les servos depuis les pins 3.3V ou
> 5V de l'ESP32. Utiliser une alimentation externe **5V / 5A minimum**.

Chaque servo a 3 fils :
- **Marron** (ou noir) → GND commun (ESP32 + alim. externe)
- **Rouge** → 5V externe (⚠ pas l'ESP32)
- **Orange** (ou jaune/blanc) → Signal PWM ESP32

| Servo | Fil signal → GPIO | Fil rouge → | Fil marron → |
|---|---|---|---|
| S1 — Torse (MG996R) | GPIO 18 | 5V externe | GND commun |
| S2 — Cou yaw (MG996R) | GPIO 19 | 5V externe | GND commun |
| S3 — Roll (MG996R) | GPIO 21 | 5V externe | GND commun |
| S4 — Pitch (MG996R) | GPIO 23 | 5V externe | GND commun |
| S5 — Bouche (SG90) | GPIO 27 | 5V externe | GND commun |

**Schéma alimentation servos :**
```
[Alim. 5V/5A] ──┬── [+5V Rail] ──┬── Servo S1 rouge
                │                 ├── Servo S2 rouge
                │                 ├── Servo S3 rouge
                │                 ├── Servo S4 rouge
                │                 └── Servo S5 rouge
                │
                └── [GND Rail] ───┬── Servo S1-S5 marron
                                  ├── GND ESP32
                                  └── GND toutes cartes

Ajouter un condensateur 1000µF 10V entre +5V Rail et GND Rail
(absorbe les pics de courant au démarrage des servos)
```

---

### 2. INMP441 — Microphone I2S

| Pin INMP441 | Connexion | Note |
|---|---|---|
| VDD | 3.3V ESP32 | |
| GND | GND | |
| SD  | GPIO 32 | Données audio (sortie micro) |
| WS  | GPIO 15 | Word Select |
| SCK | GPIO 14 | Horloge série |
| L/R | GND | Micro gauche (mettre à GND) |

---

### 3. MAX98357 — Amplificateur I2S + Haut-parleur

| Pin MAX98357 | Connexion | Note |
|---|---|---|
| VIN | 5V externe | Peut aussi prendre 3.3V (moins fort) |
| GND | GND | |
| LRC | GPIO 25 | Word Select |
| BCLK | GPIO 26 | Bit Clock |
| DIN | GPIO 22 | Données audio |
| GAIN | Laisser libre | Gain par défaut 9dB (ou GND=6dB, 3.3V=12dB) |
| SD  | Laisser libre | Pas en mode shutdown |
| **+** (sortie) | Haut-parleur + | Câble vers HP 3W 4Ω ou 8Ω |
| **-** (sortie) | Haut-parleur - | |

---

### 4. LCD 16×2 avec module I2C (PCF8574)

> Le LCD doit avoir un module I2C PCF8574 soudé derrière. Adresse par
> défaut : `0x27` (ou `0x3F` selon le module).

| Pin module I2C | Connexion |
|---|---|
| VCC | 5V externe ou 3.3V |
| GND | GND |
| SDA | GPIO 4 |
| SCL | GPIO 5 |

Vérifier l'adresse I2C avec un scanner I2C sur l'ESP32 si l'écran ne s'allume pas.

---

### 5. RTC — Module MH (DS1307 ou DS3231)

> Partage le même bus I2C que le LCD. Adresse : `0x68`.

| Pin RTC | Connexion |
|---|---|
| VCC | 3.3V ou 5V |
| GND | GND |
| SDA | GPIO 4 (même fil que LCD SDA) |
| SCL | GPIO 5 (même fil que LCD SCL) |

---

### 6. Keypad 4×4 Matrix

> Brancher les **colonnes en OUTPUT** (ESP32 pilote) et les **rangées en INPUT_PULLUP**.
> Pour les GPIO 34 et 35 (input-only) : ajouter une résistance **10kΩ entre la pin et 3.3V** (pullup externe).

```
Keypad :    C1    C2    C3    C4
             │     │     │     │
            D33   D12   D2    D0   ← GPIO ESP32 (OUTPUT)

            R1    R2    R3    R4
             │     │     │     │
           RX2   TX2   D34   D35  ← GPIO ESP32 (INPUT)
                        │     │
                      10kΩ   10kΩ  ← vers 3.3V (pullup externe)
```

| Pin Keypad | GPIO | Direction | Pullup |
|---|---|---|---|
| R1 (Row 1) | GPIO 16 (RX2) | INPUT_PULLUP | Interne |
| R2 (Row 2) | GPIO 17 (TX2) | INPUT_PULLUP | Interne |
| R3 (Row 3) | GPIO 34 | INPUT | **Externe 10kΩ → 3.3V** |
| R4 (Row 4) | GPIO 35 | INPUT | **Externe 10kΩ → 3.3V** |
| C1 (Col 1) | GPIO 33 | OUTPUT | — |
| C2 (Col 2) | GPIO 12 | OUTPUT | — |
| C3 (Col 3) | GPIO 2  | OUTPUT | — |
| C4 (Col 4) | GPIO 0  | OUTPUT | — |

---

### 7. Buzzer KSG3603

| Connexion | Détail |
|---|---|
| Pin + (signal) | GPIO 13 → résistance 100Ω → pin + buzzer |
| Pin - (GND) | GND |

---

### 8. Interrupteur (Switch)

| Connexion | Détail |
|---|---|
| Pin 1 | GPIO 36 (VP) |
| Pin 2 | GND |
| Pullup | **Externe 10kΩ entre GPIO 36 et 3.3V** |

Quand l'interrupteur est ouvert → GPIO 36 lit HIGH (3.3V via pullup)
Quand l'interrupteur est fermé → GPIO 36 lit LOW (connecté à GND)

---

### 9. Potentiomètre

| Pin Potentiomètre | Connexion |
|---|---|
| Gauche (VCC) | 3.3V |
| Droite (GND) | GND |
| Centre (signal) | GPIO 39 (VN) |

Valeur recommandée : 10kΩ

---

## Résumé alimentation

| Source | Tension | Alimente |
|---|---|---|
| Alim. externe 5V/5A | 5V | Tous les servos + rail 5V |
| Rail 5V → ESP32 VIN | 5V → 3.3V interne | ESP32, LCD, RTC, buzzer |
| 3.3V ESP32 | 3.3V | INMP441, pullups keypad/switch |
| 5V externe | 5V | MAX98357 VIN, LCD VCC optionnel |

---

## Résistances nécessaires

| Résistance | Quantité | Usage |
|---|---|---|
| 10kΩ | 3 | Pullup GPIO 34, 35 (keypad) + GPIO 36 (switch) |
| 100Ω | 1 | Buzzer série |
| Condensateur 1000µF 10V | 1 | Découplage rail servo 5V |

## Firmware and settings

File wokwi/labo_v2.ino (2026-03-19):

/*
  ╔══════════════════════════════════════════════════════════════╗
  ║  NEO — LABO V2                                               ║
  ║  Potentiomètre → Servo   |   Clavier → actions              ║
  ║  MAX98357 I2S → sons     |   Détecteur son → réaction       ║
  ╠══════════════════════════════════════════════════════════════╣
  ║  CÂBLAGE :                                                   ║
  ║  Potentiomètre  → GPIO 34  (broche centrale, 3.3V / GND)    ║
  ║  Servo signal   → GPIO 18                                    ║
  ║  MAX98357 BCLK  → GPIO 26                                    ║
  ║  MAX98357 LRC   → GPIO 25                                    ║
  ║  MAX98357 DIN   → GPIO 22                                    ║
  ║  Détecteur OUT  → GPIO 35  (module 3 broches MH-M38)        ║
  ║  Clavier lignes → GPIO 13, 14, 16, 17                       ║
  ║  Clavier cols   → GPIO 15, 12, 2, 5                         ║
  ╠══════════════════════════════════════════════════════════════╣
  ║  CLAVIER :                                                   ║
  ║   1→Do  2→Ré  3→Mi    A→Sweep servo ON/OFF                  ║
  ║   4→Fa  5→Sol 6→La    B→Servo 0°                            ║
  ║   7→Si  8→Mélodie 9→Alarme  C→Servo 90°                    ║
  ║   *→toggle clap  0→Silence  #→Reset   D→Servo 180°          ║
  ╚══════════════════════════════════════════════════════════════╝
*/

#include <ESP32Servo.h>
#include <Keypad.h>
#include <driver/i2s.h>
#include <math.h>

// ── PINS ─────────────────────────────────────────────────────────────────────
#define PIN_POT      34   // Potentiomètre (ADC1 — fonctionne sans WiFi)
#define PIN_SERVO    18
#define PIN_DET_OUT  35   // Détecteur son MH-M38 — OUT (3 broches : VCC/GND/OUT)

// ── I2S / MAX98357 ────────────────────────────────────────────────────────────
#define I2S_BCLK     26
#define I2S_LRC      25
#define I2S_DIN      22
#define SAMPLE_RATE  16000
#define AMPLITUDE    8000   // volume (max 32767 — baisse si trop fort)

// ── CLAVIER 4×4 ──────────────────────────────────────────────────────────────
const byte KP_ROWS = 4, KP_COLS = 4;
char keys[KP_ROWS][KP_COLS] = {
  {'1','2','3','A'},
  {'4','5','6','B'},
  {'7','8','9','C'},
  {'*','0','#','D'}
};
byte rowPins[KP_ROWS] = {13, 14, 16, 17};
byte colPins[KP_COLS] = {15, 12,  2,  5};
Keypad keypad = Keypad(makeKeymap(keys), rowPins, colPins, KP_ROWS, KP_COLS);

// ── SERVO ─────────────────────────────────────────────────────────────────────
Servo servo;
int  servoAngle  = 90;
bool sweepMode   = false;   // balayage automatique
int  sweepAngle  = 0;
int  sweepDir    = 1;       // +1 ou -1
unsigned long lastSweep = 0;

// ── DÉTECTION SON ─────────────────────────────────────────────────────────────
bool clapEnabled = true;
unsigned long lastClap = 0;
#define CLAP_DEBOUNCE_MS 800  // évite les déclenchements multiples

// ── NOTES (fréquences en Hz) ──────────────────────────────────────────────────
#define DO   262
#define RE   294
#define MI   330
#define FA   349
#define SOL  392
#define LA   440
#define SI   494
#define DO5  523

// Mélodie : Frère Jacques (premières mesures)
const int MELODY[]   = {DO,RE,MI,DO, DO,RE,MI,DO, MI,FA,SOL, MI,FA,SOL};
const int DURATIONS[] = {350,350,350,350, 350,350,350,350, 350,350,700, 350,350,700};
const int MELODY_LEN  = 14;

// ── FONCTIONS AUDIO ───────────────────────────────────────────────────────────

void i2sInit() {
  i2s_config_t cfg = {
    .mode                 = (i2s_mode_t)(I2S_MODE_MASTER | I2S_MODE_TX),
    .sample_rate          = SAMPLE_RATE,
    .bits_per_sample      = I2S_BITS_PER_SAMPLE_16BIT,
    .channel_format       = I2S_CHANNEL_FMT_ONLY_LEFT,
    .communication_format = I2S_COMM_FORMAT_STAND_I2S,
    .intr_alloc_flags     = 0,
    .dma_buf_count        = 8,
    .dma_buf_len          = 64,
    .use_apll             = false,
    .tx_desc_auto_clear   = true,
  };
  i2s_pin_config_t pins = {
    .bck_io_num   = I2S_BCLK,
    .ws_io_num    = I2S_LRC,
    .data_out_num = I2S_DIN,
    .data_in_num  = I2S_PIN_NO_CHANGE,
  };
  i2s_driver_install(I2S_NUM_0, &cfg, 0, NULL);
  i2s_set_pin(I2S_NUM_0, &pins);
}

// Joue une note (bloquant pendant duration_ms)
void playTone(int freq, int duration_ms) {
  const int BUF_SIZE = 256;
  int16_t buf[BUF_SIZE];
  int totalSamples = (long)SAMPLE_RATE * duration_ms / 1000;
  int played = 0;

  while (played < totalSamples) {
    int chunk = min(BUF_SIZE, totalSamples - played);
    for (int i = 0; i < chunk; i++) {
      // Enveloppe légère pour éviter les clics (5ms fade in/out)
      float env = 1.0f;
      int fadeLen = SAMPLE_RATE * 5 / 1000;
      if (played + i < fadeLen)
        env = (float)(played + i) / fadeLen;
      else if (played + i > totalSamples - fadeLen)
        env = (float)(totalSamples - played - i) / fadeLen;

      buf[i] = (int16_t)(AMPLITUDE * env * sinf(2.0f * PI * freq * (played + i) / SAMPLE_RATE));
    }
    size_t bw;
    i2s_write(I2S_NUM_0, buf, chunk * sizeof(int16_t), &bw, portMAX_DELAY);
    played += chunk;
  }
}

// Silence (vide le buffer DMA)
void silence() {
  int16_t buf[256] = {};
  size_t bw;
  for (int i = 0; i < 4; i++)
    i2s_write(I2S_NUM_0, buf, sizeof(buf), &bw, 100);
}

// Mélodie Frère Jacques
void playMelody() {
  Serial.println("♪ Frère Jacques...");
  for (int i = 0; i < MELODY_LEN; i++) {
    playTone(MELODY[i], DURATIONS[i]);
    delay(40);  // petit silence entre les notes
  }
  silence();
}

// Alarme (3 bips montants)
void playAlarm() {
  Serial.println("⚠ Alarme!");
  for (int i = 0; i < 3; i++) {
    playTone(800 + i * 300, 200);
    delay(80);
  }
  silence();
}

// Son de clap détecté (petite fanfare)
void playBip() {
  playTone(DO5, 100);
  silence();
}

// ── SERVO ─────────────────────────────────────────────────────────────────────

void setServo(int angle) {
  servoAngle = constrain(angle, 0, 180);
  servo.write(servoAngle);
  Serial.print("Servo → "); Serial.print(servoAngle); Serial.println("°");
}

// ── SETUP ─────────────────────────────────────────────────────────────────────
void setup() {
  Serial.begin(115200);

  // Servo
  servo.attach(PIN_SERVO, 500, 2400);
  servo.write(90);

  // I2S
  i2sInit();

  // Détecteur MH-M38 : OUT = LOW quand son détecté (pas de pullup interne sur GPIO 35)
  pinMode(PIN_DET_OUT, INPUT);

  // Démarrage
  Serial.println("=== NEO LABO V2 ===");
  Serial.println("Pot → Servo | Clavier → sons & servo | Détecteur → réaction");
  Serial.println("Clavier: 1-7=notes 8=mélodie 9=alarme 0=silence");
  Serial.println("         A=sweep B=0° C=90° D=180° *=clap #=reset");

  playTone(DO, 150); delay(50);
  playTone(MI, 150); delay(50);
  playTone(SOL, 250);
  silence();
  Serial.println("Prêt !");
}

// ── LOOP ──────────────────────────────────────────────────────────────────────
void loop() {

  // ── 1. POTENTIOMÈTRE → servo (sauf si sweep actif) ──────────────────────
  if (!sweepMode) {
    int raw = analogRead(PIN_POT);              // 0-4095 (12 bits)
    int angle = map(raw, 0, 4095, 0, 180);
    if (abs(angle - servoAngle) >= 2) {         // seuil anti-tremblement
      servoAngle = angle;
      servo.write(servoAngle);
    }
  }

  // ── 2. SWEEP AUTOMATIQUE ─────────────────────────────────────────────────
  if (sweepMode && millis() - lastSweep > 20) {
    sweepAngle += sweepDir * 2;
    if (sweepAngle >= 180) { sweepAngle = 180; sweepDir = -1; }
    if (sweepAngle <= 0)   { sweepAngle = 0;   sweepDir =  1; }
    servo.write(sweepAngle);
    lastSweep = millis();
  }

  // ── 3. DÉTECTION SON ────────────────────────────────────────────────────
  if (clapEnabled) {
    // DO = LOW quand son détecté sur la plupart des modules KY-038
    // Si ça ne marche pas, essaie d'inverser : (digitalRead == HIGH)
    bool soundDetected = (digitalRead(PIN_DET_OUT) == LOW);  // LOW = son détecté sur MH-M38

    if (soundDetected && millis() - lastClap > CLAP_DEBOUNCE_MS) {
      lastClap = millis();
      Serial.println(">> Son détecté ! <<");

      // Action : servo fait un petit sursaut
      int oldAngle = sweepMode ? sweepAngle : servoAngle;
      servo.write(constrain(oldAngle + 30, 0, 180));
      delay(200);
      servo.write(oldAngle);
      playBip();
    }
  }

  // ── 4. CLAVIER ───────────────────────────────────────────────────────────
  char key = keypad.getKey();
  if (!key) return;

  Serial.print("Touche: "); Serial.println(key);

  switch (key) {
    // Notes
    case '1': playTone(DO,  400); silence(); break;
    case '2': playTone(RE,  400); silence(); break;
    case '3': playTone(MI,  400); silence(); break;
    case '4': playTone(FA,  400); silence(); break;
    case '5': playTone(SOL, 400); silence(); break;
    case '6': playTone(LA,  400); silence(); break;
    case '7': playTone(SI,  400); silence(); break;
    case '8': playMelody(); break;
    case '9': playAlarm();  break;
    case '0': silence(); Serial.println("Silence"); break;

    // Servo positions fixes
    case 'B': sweepMode = false; setServo(0);   break;
    case 'C': sweepMode = false; setServo(90);  break;
    case 'D': sweepMode = false; setServo(180); break;

    // Sweep toggle
    case 'A':
      sweepMode = !sweepMode;
      sweepAngle = servoAngle;
      Serial.println(sweepMode ? "Sweep: ON" : "Sweep: OFF");
      break;

    // Toggle détection clap
    case '*':
      clapEnabled = !clapEnabled;
      Serial.println(clapEnabled ? "Détection son: ON" : "Détection son: OFF");
      break;

    // Reset
    case '#':
      sweepMode   = false;
      clapEnabled = true;
      setServo(90);
      silence();
      Serial.println("== RESET ==");
      break;
  }
}

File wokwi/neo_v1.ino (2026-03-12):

/*  ╔══════════════════════════════════════════════════════════╗
    ║  NEO V1  —  ESP32 firmware                               ║
    ║  Contrôle : 4x MG996R (Pan+Tilt), LCD I2C, Clavier 4x4  ║
    ║  Audio    : INMP441 (mic I2S) + MAX98357 (speaker I2S)   ║
    ║  Comm     : WiFi + MQTT                                   ║
    ╚══════════════════════════════════════════════════════════╝

    Wokwi simulation : définir #define WOKWI_SIM pour désactiver I2S
    Hardware réel    : commenter le define ci-dessous
*/

// #define WOKWI_SIM   // ← décommenter pour simuler dans Wokwi

// ── Includes ──────────────────────────────────────────────────────────────────
#include <Arduino.h>
#include <WiFi.h>
#include <PubSubClient.h>
#include <ESP32Servo.h>
#include <Wire.h>
#include <LiquidCrystal_I2C.h>
#include <Keypad.h>
#include <ArduinoJson.h>

#ifndef WOKWI_SIM
  #include <driver/i2s.h>
#endif

// ── WiFi & MQTT ───────────────────────────────────────────────────────────────
const char* WIFI_SSID     = "TON_SSID";
const char* WIFI_PASSWORD = "TON_MOT_DE_PASSE";
const char* MQTT_SERVER   = "72.61.111.8";
const int   MQTT_PORT     = 1883;
const char* MQTT_CLIENT   = "neo-esp32";

const char* TOPIC_CMD    = "neo/commandes";
const char* TOPIC_STATUS = "neo/status";
const char* TOPIC_AUDIO  = "neo/audio/data";
const char* TOPIC_MIC    = "neo/audio/mic";

// ── GPIO Pinout ───────────────────────────────────────────────────────────────
// Servos
#define PIN_PAN_A   18
#define PIN_PAN_B   19
#define PIN_TILT_A  23
#define PIN_TILT_B   4

// LCD I2C
#define LCD_SDA 21
#define LCD_SCL 22
#define LCD_ADDR 0x27

// Clavier 4×4
#define KP_ROWS 4
#define KP_COLS 4
byte kpRowPins[KP_ROWS] = {13, 14, 16, 17};
byte kpColPins[KP_COLS] = {15, 12,  2,  5};

// Buzzer (Wokwi) / Speaker (GPIO 25 partagé)
#define PIN_BUZZER 25

#ifndef WOKWI_SIM
  // I2S Microphone INMP441
  #define I2S_MIC_SCK  32
  #define I2S_MIC_WS   33
  #define I2S_MIC_SD   34

  // I2S Speaker MAX98357
  #define I2S_SPK_BCLK 25
  #define I2S_SPK_LRC  26
  #define I2S_SPK_DIN  27
#endif

// ── Servo limits ──────────────────────────────────────────────────────────────
#define SERVO_MIN  500   // µs
#define SERVO_MAX  2500  // µs
#define PAN_MIN    30
#define PAN_MAX    150
#define PAN_CENTER 90
#define TILT_MIN   50
#define TILT_MAX   130
#define TILT_CENTER 90
#define STEP        15   // degrés par commande

// ── Objects ───────────────────────────────────────────────────────────────────
Servo servoPanA, servoPanB, servoTiltA, servoTiltB;
LiquidCrystal_I2C lcd(LCD_ADDR, 16, 2);

const char keys[KP_ROWS][KP_COLS] = {
  {'1','2','3','A'},
  {'4','5','6','B'},
  {'7','8','9','C'},
  {'*','0','#','D'}
};
Keypad keypad = Keypad(makeKeymap(keys), kpRowPins, kpColPins, KP_ROWS, KP_COLS);

WiFiClient   wifiClient;
PubSubClient mqttClient(wifiClient);

// ── State ─────────────────────────────────────────────────────────────────────
int currentPan  = PAN_CENTER;
int currentTilt = TILT_CENTER;

// ── Helpers ───────────────────────────────────────────────────────────────────
void setHead(int pan, int tilt) {
  pan  = constrain(pan,  PAN_MIN,  PAN_MAX);
  tilt = constrain(tilt, TILT_MIN, TILT_MAX);
  currentPan  = pan;
  currentTilt = tilt;
  servoPanA.write(pan);
  servoPanB.write(180 - pan);   // miroir
  servoTiltA.write(tilt);
  servoTiltB.write(180 - tilt); // miroir
}

void lcdPrint(const char* line1, const char* line2 = "") {
  lcd.clear();
  lcd.setCursor(0, 0); lcd.print(line1);
  lcd.setCursor(0, 1); lcd.print(line2);
}

void publishStatus(const char* state) {
  StaticJsonDocument<128> doc;
  doc["state"] = state;
  doc["pan"]   = currentPan;
  doc["tilt"]  = currentTilt;
  char buf[128];
  serializeJson(doc, buf);
  mqttClient.publish(TOPIC_STATUS, buf);
}

// ── Buzzer beep (Wokwi) ───────────────────────────────────────────────────────
#ifdef WOKWI_SIM
void beep(int freq, int ms) {
  tone(PIN_BUZZER, freq, ms);
  delay(ms + 10);
}
#endif

// ── MQTT callback ─────────────────────────────────────────────────────────────
void onMqttMessage(char* topic, byte* payload, unsigned int length) {
  // Audio data → play raw PCM
  if (strcmp(topic, TOPIC_AUDIO) == 0) {
#ifndef WOKWI_SIM
    size_t written = 0;
    i2s_write(I2S_NUM_0, payload, length, &written, portMAX_DELAY);
#endif
    return;
  }

  // Commands JSON
  StaticJsonDocument<256> doc;
  if (deserializeJson(doc, payload, length) != DeserializationError::Ok) return;

  const char* action = doc["action"] | "";

  if      (strcmp(action, "tete_gauche")  == 0) setHead(currentPan - STEP, currentTilt);
  else if (strcmp(action, "tete_droite")  == 0) setHead(currentPan + STEP, currentTilt);
  else if (strcmp(action, "tete_haut")    == 0) setHead(currentPan, currentTilt - STEP);
  else if (strcmp(action, "tete_bas")     == 0) setHead(currentPan, currentTilt + STEP);
  else if (strcmp(action, "tete_centre")  == 0) setHead(PAN_CENTER, TILT_CENTER);
  else if (strcmp(action, "repos")        == 0) {
    setHead(PAN_CENTER, TILT_CENTER);
    lcdPrint("NEO READY", "");
  }
  else if (strcmp(action, "servo_direct") == 0) {
    int pan  = doc["pan"]  | currentPan;
    int tilt = doc["tilt"] | currentTilt;
    setHead(pan, tilt);
  }
  else if (strcmp(action, "buzzer_test")  == 0) {
#ifdef WOKWI_SIM
    beep(523, 120); beep(659, 120); beep(784, 200);
#endif
    lcdPrint("BUZZER TEST", "");
  }
  else if (strcmp(action, "lcd") == 0) {
    const char* texte = doc["texte"] | "";
    char l1[17], l2[17];
    strncpy(l1, texte,      16); l1[16] = '\0';
    strncpy(l2, texte + 16, 16); l2[16] = '\0';
    lcdPrint(l1, l2);
  }
  else if (strcmp(action, "dire") == 0) {
    // Audio TTS arrivera via TOPIC_AUDIO
    // Affiche le texte sur le LCD en attendant
    const char* texte = doc["texte"] | "";
    char l1[17];
    strncpy(l1, texte, 16); l1[16] = '\0';
    lcdPrint("Neo:", l1);
#ifdef WOKWI_SIM
    beep(880, 200);
#endif
  }

  publishStatus("ok");
}

// ── WiFi ──────────────────────────────────────────────────────────────────────
void connectWifi() {
  WiFi.begin(WIFI_SSID, WIFI_PASSWORD);
  lcdPrint("WiFi...", "");
  while (WiFi.status() != WL_CONNECTED) {
    delay(500);
  }
  lcdPrint("WiFi OK", WiFi.localIP().toString().c_str());
  delay(1000);
}

// ── MQTT reconnect ────────────────────────────────────────────────────────────
void reconnectMqtt() {
  while (!mqttClient.connected()) {
    lcdPrint("MQTT...", "");
    if (mqttClient.connect(MQTT_CLIENT)) {
      mqttClient.subscribe(TOPIC_CMD);
      mqttClient.subscribe(TOPIC_AUDIO);
      lcdPrint("Neo pret!", "");
      publishStatus("ready");
    } else {
      delay(3000);
    }
  }
}
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

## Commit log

2026-03-12 Setup Neo robot AI project — full initial codebase
    - app.py: Flask + Socket.IO Control Center connecting to MQTT broker
    and OpenClaw WebSocket Gateway for live servo control and chat
    - templates/index.html: dark-theme web UI with D-pad head control,
    LCD preview, and real-time chat with Neo (OpenClaw AI)
    - neo_bridge.py: audio pipeline — INMP441 mic → STT (faster-whisper)
    → OpenClaw → TTS (edge-tts) → MAX98357 speaker via MQTT
    - wokwi/neo_v1.ino: ESP32 firmware with servo control (4x MG996R),
    LCD I2C, 4x4 keypad, MQTT command handler, I2S audio (guarded by
    WOKWI_SIM flag for simulation compatibility)
    - wokwi/diagram.json: Wokwi circuit — ESP32 + 4 servos + LCD + keypad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
    [app.py, neo_v1.ino]
2026-03-12 Refonte complète — Neo Control Center v2
    Interface web :
    - SPA avec sidebar de navigation (5 sections)
    - Tableau de bord : cartes de statut animées, actions rapides, feed d'activité
    - Communication : chat animé avec Neo, phrases rapides, indicateur "réflexion"
    - Corps : D-pad avec maintien enfoncé, sliders précis Pan/Tilt, visualiseur SVG
    de position de la tête, raccourcis clavier (flèches/espace/R), poses rapides
    - Affichage LCD : preview live, texte libre, 6 presets
    - Diagnostics : tests individuels (MQTT, OpenClaw, servos, LCD, buzzer, complet),
    commande MQTT manuelle, console de logs colorée temps réel
    Backend app.py :
    - Système de logs avec deque (400 entrées), émis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
    [app.py, neo_v1.ino]
2026-03-12 React + Vite frontend with modern dark blue theme
    Frontend (React + Vite):
    - 5 sections: Dashboard, Communication, Corps, LCD, Diagnostics
    - Modern design: dark greys/blacks + blue accents, Inter font, smooth animations
    - NeoContext provider for shared state (socket, servos, logs, chat, tests)
    - Dashboard: connection status cards, quick actions, activity feed
    - Communication: animated chat with Neo, quick phrases, thinking indicator
    - Corps: SVG head position visualizer, D-pad with hold-to-repeat, precise
    Pan/Tilt sliders, keyboard shortcuts, quick poses
    - LCD: realistic LCD preview with scanlines, text input, 6 presets
    - Diagnostics: individual component tests with status badges, system i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
    [app.py]
2026-03-12 Docker: ajout du déploiement complet pour VPS
    - Dockerfile.frontend : build multi-stage Node 20 + Nginx 1.27-alpine
    - Dockerfile.backend : Python 3.11-slim avec utilisateur non-root
    - nginx/nginx.conf : proxy Socket.IO (WebSocket) + API + SPA fallback
    - docker-compose.yml : orchestration frontend/backend + bloc MQTT optionnel
    - .dockerignore : exclusion node_modules, venv, wokwi, secrets
    https://claude.ai/code/session_01UgVUQPgbULkMdKYCdxANgK
2026-03-12 Docker: migration port 8000, dist/ build, placeholders clairs
    - app.py : port configurable via $PORT (défaut 8000), SECRET_KEY depuis env
    - vite.config.js : outDir '../static' → 'dist' (standard Docker)
    - Dockerfile.frontend : COPY depuis frontend/dist (multi-stage node:20-alpine + nginx:alpine)
    - Dockerfile.backend : EXPOSE 8000, utilisateur non-root neo
    - nginx/nginx.conf : proxy Socket.IO + API vers backend:8000, timeout WS 86400s
    - docker-compose.yml : ports 8000:8000, placeholders explicites SECRET_KEY/MQTT/OpenClaw
    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
2026-03-12 Fix: npm ci → npm install (pas de package-lock.json dans le repo)
    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
2026-03-12 Fix: port frontend 80 → 8080 (port 80 déjà occupé sur le VPS)
    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
2026-03-12 Fix nginx: resolver Docker 127.0.0.11 + variable upstream (DNS runtime)
    Nginx résolvait "backend" au démarrage — échoue si le réseau DNS
    Docker n'est pas encore prêt. Le resolver 127.0.0.11 + set $backend
    force la résolution à chaque requête.
    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
2026-03-12 feat: add authentication + fix OpenClaw/MQTT config
    - Add password-based login page (APP_PASSWORD env var)
    - Protect Socket.IO connections (reject unauthenticated)
    - Add /api/login, /api/logout, /api/me routes
    - Socket only connects after successful login
    - Logout button in topbar
    - Fix NEO_MQTT_HOST and NEO_OPENCLAW_WS in docker-compose.yml (72.61.111.8)
    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
    [app.py]
2026-03-12 refactor: invert OpenClaw architecture — Neo exposes REST API
    OpenClaw now calls Neo (not the reverse):
    - GET /api/neo/pending → OpenClaw polls for user messages
    - POST /api/neo/message → OpenClaw sends replies {"text": "..."}
    - Remove websocket-client outbound connection to OpenClaw
    - openclaw_ok based on last poll timestamp (60s window)
    - Optional OPENCLAW_API_KEY header auth
    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
    [app.py]
2026-03-12 perf: long polling sur /api/neo/pending (~2 req/min au lieu de 20)
    Bloque la requête jusqu'à 25s en attendant un message.
    Réduit drastiquement la consommation de tokens OpenClaw.
    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
2026-03-12 feat: SSE push pour OpenClaw — zéro polling quand inactif
    Remplace le long polling par Server-Sent Events:
    - GET /api/neo/stream : connexion persistante, Neo pousse les messages
    - OpenClaw reçoit instantanément sans jamais faire de requête à vide
    - keepalive toutes les 30s pour maintenir la connexion
    - /api/neo/pending gardé comme fallback
    - nginx: route SSE sans buffer, timeout 1h
    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
    [app.py]
2026-03-12 Optimize app: SSE connection detection, chat history, UX improvements
    - app.py: real-time OpenClaw detection via SSE queue count, remove stale openclaw_ok global,
    include chat history in SSE messages, store Neo replies in chat_history
    - NeoContext: 45s chat timeout with error message, clearChat() helper
    - BodyControl: fix D-pad pressed visual state (useState instead of ref)
    - Communication: clear chat button, dynamic input placeholder, error message styling
    - Diagnostics: update OpenClaw info from WS:18789 to SSE /api/neo/stream
    - App.css: add msg-error style for timeout messages
    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
    [app.py]
2026-03-12 Add full mobile responsive layout
    - Bottom navigation bar replaces left sidebar on mobile (≤640px)
    - App shell reflows to 3-row grid: topbar / content / bottom-nav
    - D-pad buttons enlarged to 72px for touch
    - Hide logo subtitle and conn pills in topbar on mobile
    - Status cards: 2+1 layout instead of 3-col
    - Body/LCD/Diagnostics layouts collapse to single column
    - Chat height recalculated for bottom nav
    - Login card scales to 92vw on mobile
    - Logout button hides text label on mobile (icon only)
    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
2026-03-13 feat: connecter OpenClaw via API HTTP OpenAI-compatible
    - Remplace le système SSE/polling par un appel HTTP direct à OpenClaw
    sur /v1/chat/completions avec streaming token par token
    - app.py : supprime les endpoints /api/neo/stream, /api/neo/pending,
    /api/neo/message ; ajoute _openclaw_stream_tokens() et détection
    de statut OpenClaw via ping /v1/models
    - neo_bridge.py : remplace le WebSocket par requests HTTP POST
    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
2026-03-13 fix: use eventlet.monkey_patch and start_background_task for SocketIO threads
    - Add eventlet.monkey_patch() before all other imports to properly patch stdlib
    - Replace threading.Thread with socketio.start_background_task() in all SocketIO
    event handlers so emissions from background tasks work correctly
    - Fixes chat timeout: tokens were emitted into a dead thread context
    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
    [app.py]
2026-03-13 feat(chat): refonte UI inspirée Claude/ChatGPT
    - Streaming token par token avec curseur clignotant
    - Rendu Markdown (code blocks, listes, gras, liens) via marked.js
    - Textarea auto-resize (Entrée=envoyer, Maj+Entrée=saut de ligne)
    - Bouton Stop pour interrompre la génération
    - Bouton Copier au survol de chaque message
    - Avatars et bulles style ChatGPT (utilisateur droite / Neo gauche)
    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
2026-03-13 feat: add persistent chat memory across sessions
    - Save chat history to /app/data/chat_history.json (Docker volume)
    - Load history on startup (deque maxlen 500)
    - Send full history to client on socket connect via chat_history_init
    - Add /api/chat/clear endpoint; clearChat() now also clears server-side
    - Show date separators between messages from different days
    - Show date+time for messages older than today
    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
2026-03-13 fix: correct chat memory permissions and Fragment layout bug
    - Dockerfile.backend: pre-create /app/data with neo ownership so the
    named volume is writable by the neo user (was silently failing)
    - app.py: log _save_chat errors instead of silently ignoring them
    - Communication.jsx: use Fragment instead of div wrapper to preserve
    flex alignment (align-self: flex-end for user messages)
    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
    [app.py]
2026-03-13 docs: add comprehensive hardware overview for Neo V1
    - Full GPIO pinout for ESP32 (I2S mic+amp, 5 servos, I2C, keypad, etc.)
    - Power supply analysis (4x MG996R need 5V/5A external — LiPo insufficient)
    - Component decision table (V1 / V2 / V3 / not used)
    - Mechanical assembly diagram (base → torse → cou → tête)
    - Shopping list for missing parts (PSU, speaker, I2C LCD module)
    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
2026-03-13 docs: add complete wiring guide and Wokwi diagram for Neo V1
    - neo-wiring-guide.md: exact pin-by-pin connections for all components
    (INMP441, MAX98357, 5 servos, LCD I2C, RTC, keypad 4x4, buzzer,
    switch, potentiometer) with power supply schematic
    - wokwi/diagram.json: importable Wokwi diagram (wokwi.com) showing
    ESP32 + servos + LCD + RTC + keypad + buzzer + switch + pot
    - Updated neo-hardware-overview.md GPIO table with correct final plan
    (GPIO 34/35/36 input-only, external pullups documented)
    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
2026-03-13 docs(wokwi): add sketch.ino and libraries.txt for complete Wokwi project
    - sketch.ino: full test sketch (servos, LCD, keypad, RTC, buzzer, switch, pot)
    with startup animation, keypad controls, switch/pot live control
    - libraries.txt: ESP32Servo + LiquidCrystal_I2C + Keypad + RTClib
    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
    [sketch.ino]
2026-03-13 fix(wokwi): correct pin names so all wires appear in simulation
    Bugs in diagram.json:
    - esp:RX2 / esp:TX2 → esp:D16 / esp:D17 (Wokwi naming)
    - esp:VN / esp:VP were swapped for switch/pot; fixed to D36/D39
    - wokwi-slide-switch sw:2 (invalid) → wokwi-pushbutton sw:1.l/sw:2.l
    - Correct VP=GPIO36, VN=GPIO39 in wiring-guide.md + hardware-overview.md
    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
2026-03-13 Add STL scaling script and update 3D spec for 250mm Ultron head
    - scale_ultron_head.py: Windows script to extract zip, auto-detect full
    head STL, scale all pieces to 250mm height, and report dimensions
    for Fusion 360 (cage internal measurements)
    - neo-3d-design-spec.md (V2): updated all piece dimensions to match
    250mm head target; added cable routing specs, Bambu A1 compatibility
    table, and detailed assembly checklist
    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
2026-03-13 feat: generate 5 structural STL pieces for Neo robot via CadQuery
    - neo_base.stl : 200×160×100 mm, logements ESP32/LCD/clavier/S1
    - neo_buste.stl : trapèze 120→80 mm, hauteur 130 mm, horn S1/S2
    - neo_cou.stl : cylindre Ø65×80 mm creux, logement S3 latéral
    - neo_support_tete.stl : croix 160×90×50 mm, logement S4 + palier M4
    - neo_cage_interne.stl : anneau Ø170 mm + 2 bras, horn S4 + palier
    Toutes les pièces incluent : passages câbles, trous M3/M4,
    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
    [neo_base.stl, neo_buste.stl, neo_cage_interne.stl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]
2026-03-19 feat: add Labo V1 learning sketch (servo + LEDs + LCD + keypad)
    Sketch standalone sans WiFi/MQTT pour débuter :
    - 4x4 keypad: touches 1-9 angles servo, A/B/C LEDs, D all, #reset, *menu
    - LCD 16x2 I2C: affiche angle servo + état LEDs en temps réel
    - 3 LEDs sur GPIO 26/27/32
    - Servo sur GPIO 18 (pulse 500-2400µs)
    + Guide câblage complet docs/labo-v1-wiring.md
    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
    [labo_v1.ino]
2026-03-19 feat: Labo V2 — potentiomètre servo + MAX98357 I2S + détecteur son + clavier
    - Potentiomètre GPIO 34 → servo en temps réel (filtre anti-tremblement)
    - MAX98357 I2S (GPIO 26/25/22) : notes Do→Si, mélodie Frère Jacques, alarme
    - Détecteur son GPIO 35 : clap → sursaut servo + bip (débounce 800ms)
    - Clavier 4x4 : 1-7 notes, 8 mélodie, 9 alarme, A sweep, B/C/D positions
    - Mode sweep servo non-bloquant (millis), toggle via touche A
    - Guide câblage complet docs/labo-v2-wiring.md
    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
2026-03-19 fix: détecteur son 3 broches MH-M38 (supprime AO/GPIO36, rename PIN_DET_OUT)
    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
    [labo_v2.ino]
2026-04-06 Expand local setup guide with step-by-step PC and ESP32 instructions
